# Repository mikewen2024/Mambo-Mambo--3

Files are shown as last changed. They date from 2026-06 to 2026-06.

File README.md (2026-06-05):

# Mambo - 1lb Combat Robot, Custom ESC Layout

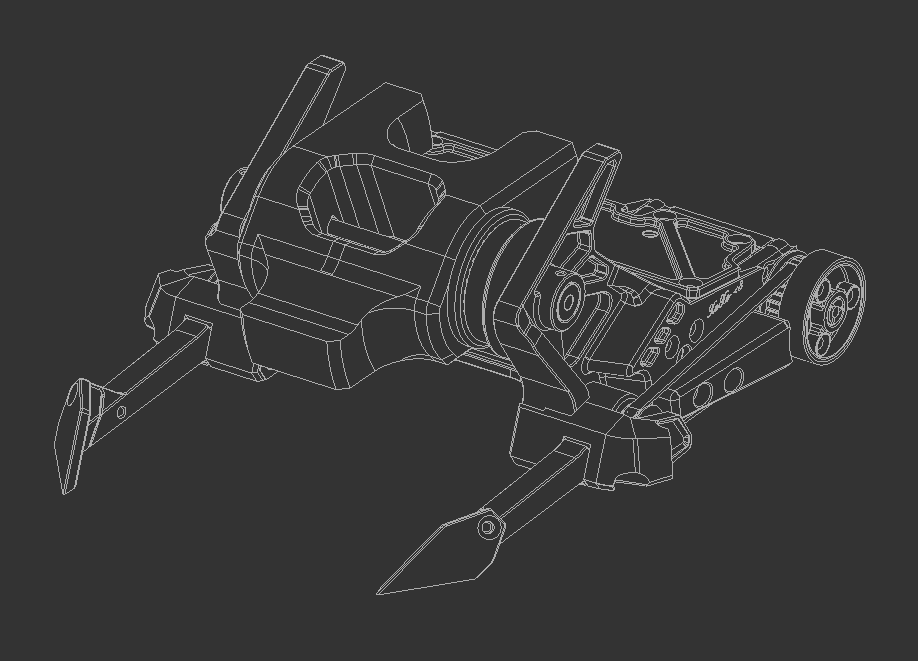
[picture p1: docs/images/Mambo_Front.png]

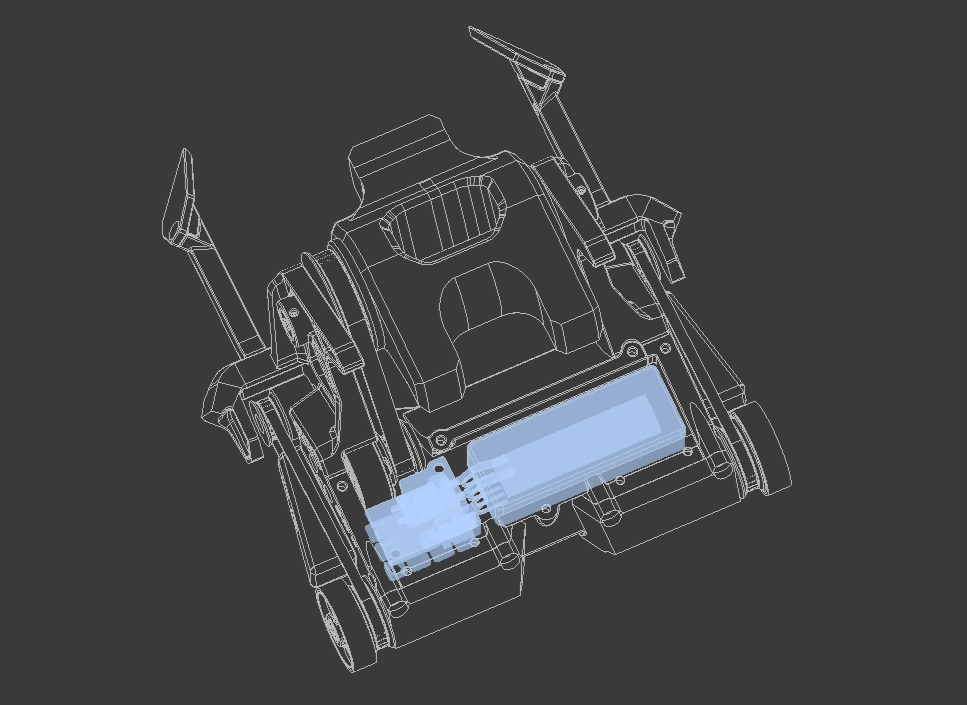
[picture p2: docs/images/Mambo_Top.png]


A 1lb plastic (plantweight) vertical spinner combat robot. I thought I'd finally try building a "meta archetype" robot after giving myself a fundamental handicap for my other 1lb combat robot projects. For the motor controller on the weapon system, there's a notable gap in the current capacities for well-known AM32-firmware BLDC motor controllers (above 35A). I also wanted to try out some alternate ESC architectures, the key features are listed below:

**Key system features:** STSPIN32F0ATR BLDC-control specific MCU (eliminates need for standalone gate driver IC), IAUC60N04S6L030H half-bridge IC for lower internal resistance, built-in TVS diodes and bulk capacitance, stable 8V 7.5A-capable output for brushed motor drivers, tight packaging and shock resistant mounting

I didn't bother making a dual brushed motor ESC for the drive system because there were already commercially-available boards that fit within my packaging constraints. Feel free to check out the corresponding technical blog [here](https://future-wool-0d5.notion.site/Mambo-1lb-Combat-Robot-375e4d628bf38082a3adc446fecd4852?pvs=74) :)

---

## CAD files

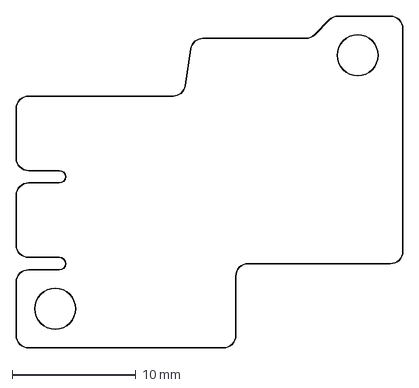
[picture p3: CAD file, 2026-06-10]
hardware/kicad/Outlines/Top PCB Outline.dxf
31.2 x 26.8 mm

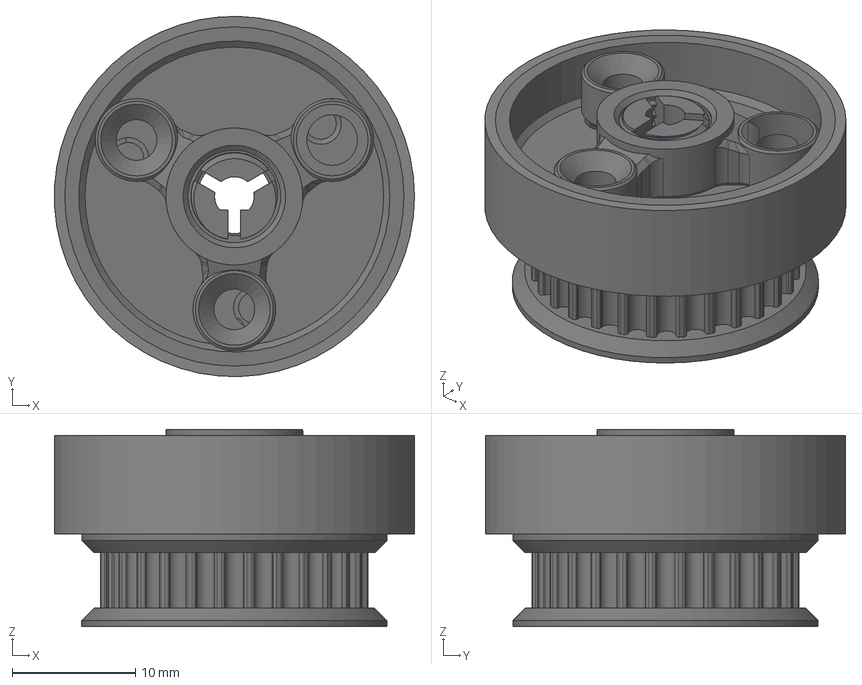
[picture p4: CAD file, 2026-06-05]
mechanical/Back Wheels.step
29.2 x 29.2 x 16.0 mm
Tightening Nut
Wheel

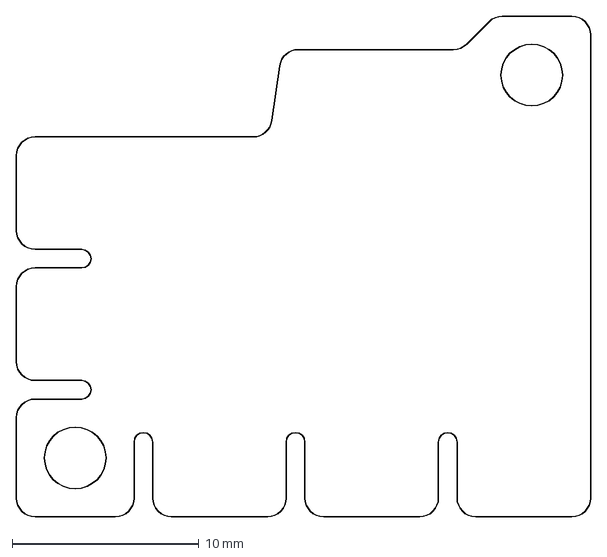
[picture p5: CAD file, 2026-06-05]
hardware/kicad/Outlines/Bottom PCB Outline.dxf
30.7 x 26.8 mm

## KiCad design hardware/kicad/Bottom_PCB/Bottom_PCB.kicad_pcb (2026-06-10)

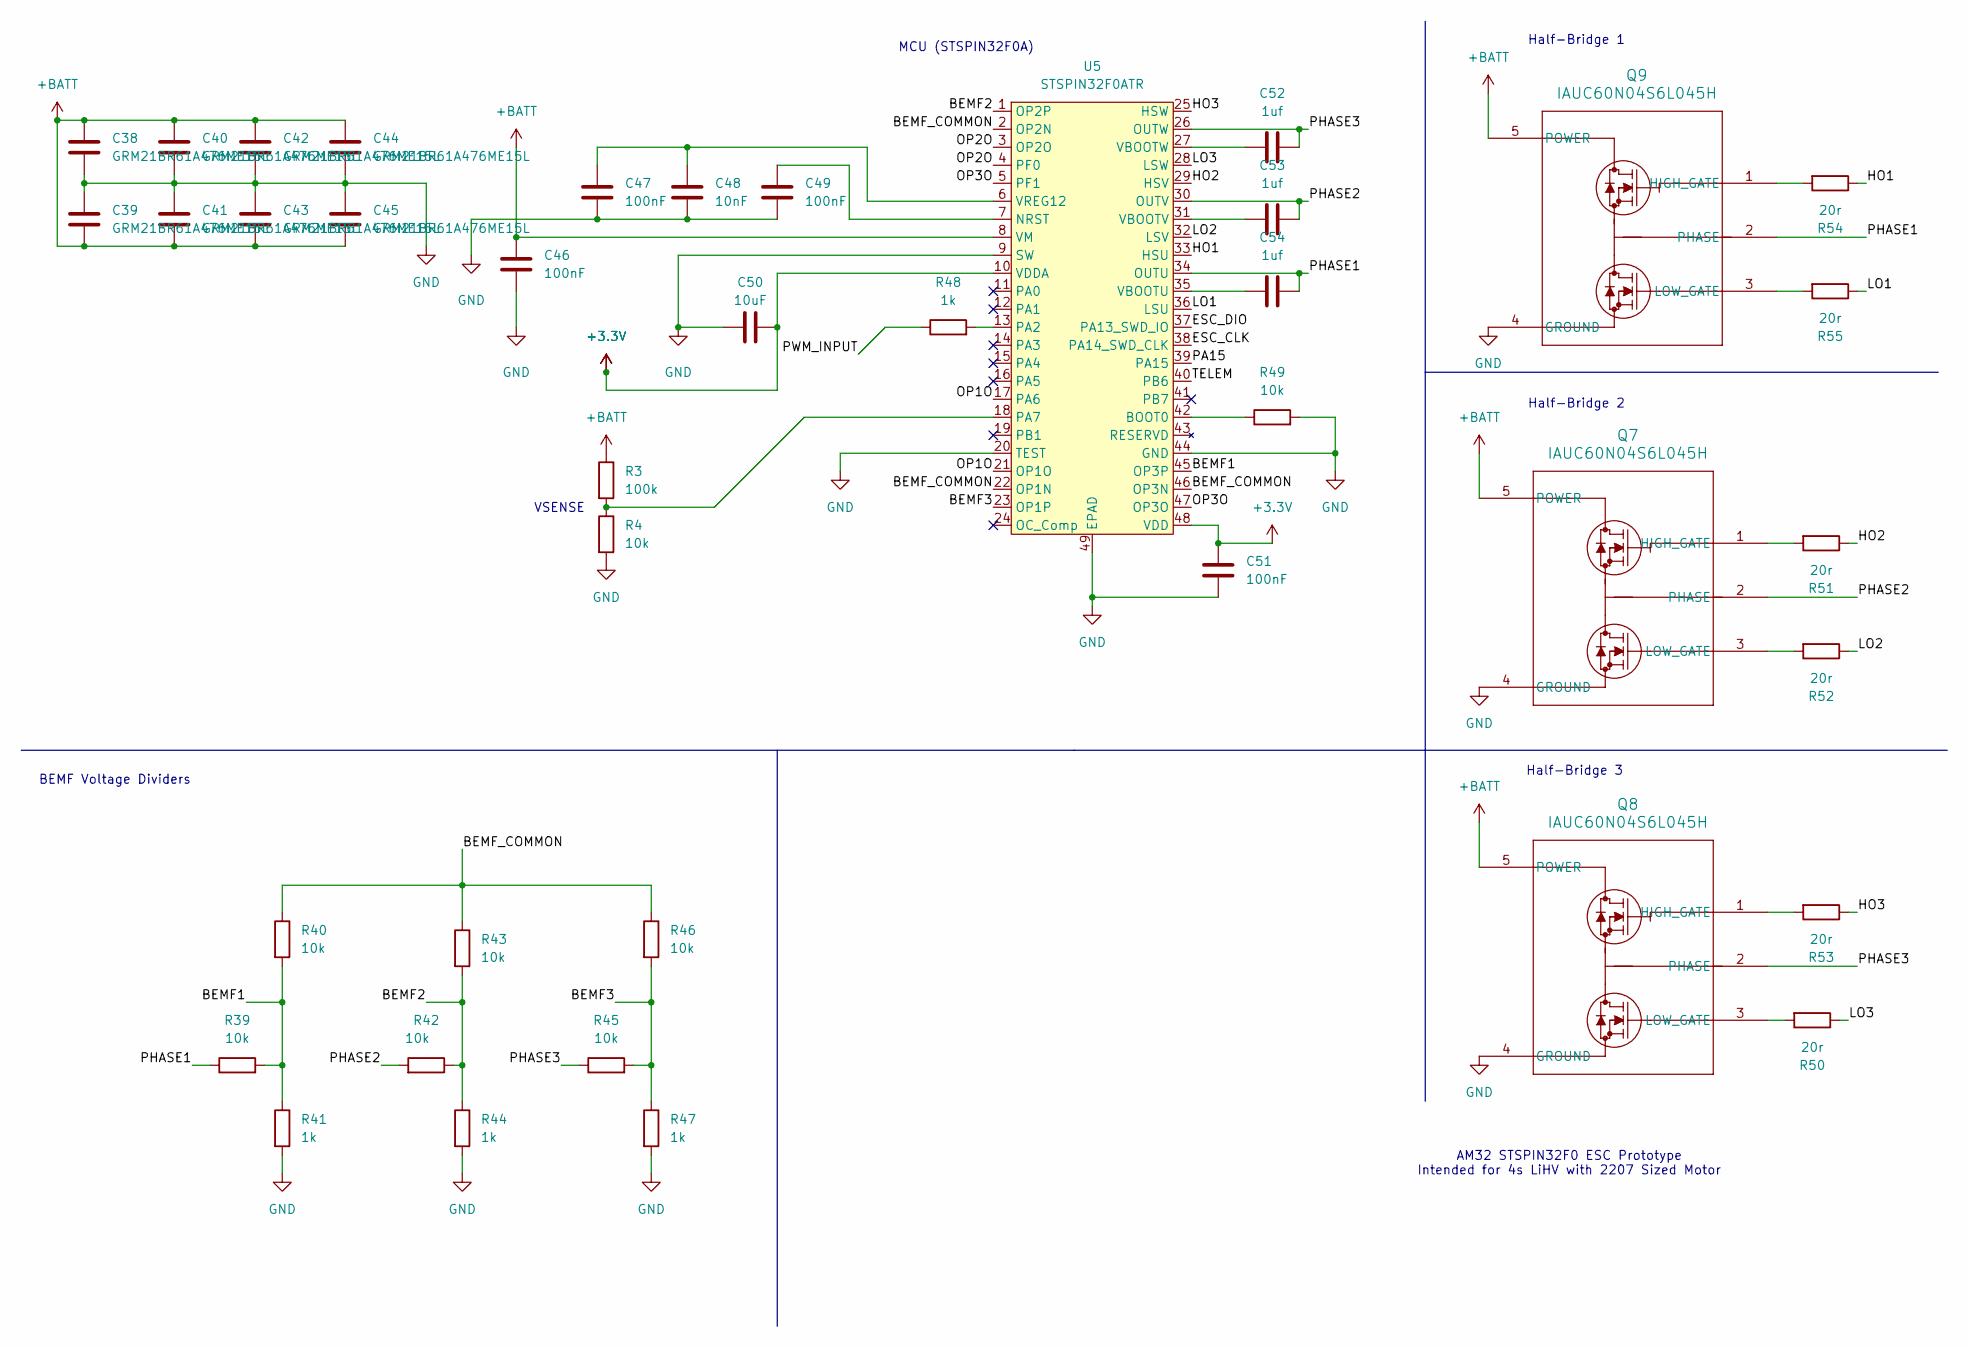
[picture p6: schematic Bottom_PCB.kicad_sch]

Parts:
C38, C39, C40, C41, C42, C43, C44, C45: GRM21BR61A476ME15L; C_0805_2012Metric
C46, C47, C49, C51: 100nF; C_0402_1005Metric_Pad0.74x0.62mm_HandSolder
C48: 10nF; C_0402_1005Metric_Pad0.74x0.62mm_HandSolder
C50: 10uF; C_0402_1005Metric_Pad0.74x0.62mm_HandSolder
C52, C53, C54: 1uf; C_0402_1005Metric_Pad0.74x0.62mm_HandSolder
Q7, Q8, Q9: IAUC60N04S6L045H; Infineon_PG-TDSON-8_56
R3: 100k; R_0402_1005Metric_Pad0.72x0.64mm_HandSolder
R4, R39, R40, R42, R43, R45, R46, R49: 10k; R_0402_1005Metric_Pad0.72x0.64mm_HandSolder
R41, R44, R47, R48: 1k; R_0402_1005Metric_Pad0.72x0.64mm_HandSolder
R50, R51, R52, R53, R54, R55: 20r; R_0402_1005Metric_Pad0.72x0.64mm_HandSolder
U5: STSPIN32F0ATR; QFN-48-1EP_7x7mm_P0.5mm_EP3.5x3.5mm

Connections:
+3.3V: C50.1, C51.1, U5.10 (VDDA), U5.48 (VDD)
+BATT: C38.1, C39.2, C40.1, C41.2, C42.1, C43.2, C44.1, C45.2, C46.1, Q7.5 (POWER), Q8.5 (POWER), Q9.5 (POWER), R3.1, U5.8 (VM)
/BEMF1: R39.2, R40.2, R41.1, U5.45 (OP3P)
/BEMF2: R42.1, R43.2, R44.1, U5.1 (OP2P)
/BEMF3: R45.2, R46.2, R47.1, U5.23 (OP1P)
/BEMF_COMMON: R40.1, R43.1, R46.1, U5.2 (OP2N), U5.22 (OP1N), U5.46 (OP3N)
/ESC_CLK: U5.38 (PA14_SWD_CLK)
/ESC_DIO: U5.37 (PA13_SWD_IO)
/HO1: R54.1, U5.33 (HSU)
/HO2: R51.1, U5.29 (HSV)
/HO3: R53.1, U5.25 (HSW)
/LO1: R55.1, U5.36 (LSU)
/LO2: R52.1, U5.32 (LSV)
/LO3: R50.1, U5.28 (LSW)
/OP1O: U5.17 (PA6), U5.21 (OP1O)
/OP2O: U5.3 (OP2O), U5.4 (PF0)
/OP3O: U5.5 (PF1), U5.47 (OP3O)
/PA15: U5.39 (PA15)
/PHASE1: C54.2, Q9.2 (PHASE), R39.1, U5.34 (OUTU)
/PHASE2: C53.2, Q7.2 (PHASE), R42.2, U5.30 (OUTV)
/PHASE3: C52.2, Q8.2 (PHASE), R45.1, U5.26 (OUTW)
/PWM_INPUT: R48.1; also elsewhere on the board
/TELEM: U5.40 (PB6)
GND: C38.2, C39.1, C40.2, C41.1, C42.2, C43.1, C44.2, C45.1, C46.2, C47.2, C48.2, C49.2, C50.2, C51.2, Q7.4 (GROUND), Q8.4 (GROUND), Q9.4 (GROUND), R4.2, R41.2, R44.2, R47.2, R49.2, U5.9 (SW), U5.20 (TEST), U5.44 (GND), U5.49 (EPAD)
unnamed: Q7.1 (HIGH_GATE), R51.2
unnamed: Q7.3 (LOW_GATE), R52.2
unnamed: Q8.1 (HIGH_GATE), R53.2
unnamed: Q8.3 (LOW_GATE), R50.2
unnamed: Q9.1 (HIGH_GATE), R54.2
unnamed: Q9.3 (LOW_GATE), R55.2
unnamed: R49.1, U5.42 (BOOT0)
unnamed: C49.1, U5.7 (NRST)
unnamed: R48.2, U5.13 (PA2)
unnamed: R3.2, R4.1, U5.18 (PA7)
unnamed: C54.1, U5.35 (VBOOTU)
unnamed: C53.1, U5.31 (VBOOTV)
unnamed: C52.1, U5.27 (VBOOTW)
unnamed: C47.1, C48.1, U5.6 (VREG12)

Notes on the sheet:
AM32 STSPIN32F0 ESC Prototype Intended for 4s LiHV with 2207 Sized Motor
BEMF Voltage Dividers
Half-Bridge 3
Half-Bridge 1
MCU (STSPIN32F0A)
VSENSE
Half-Bridge 2

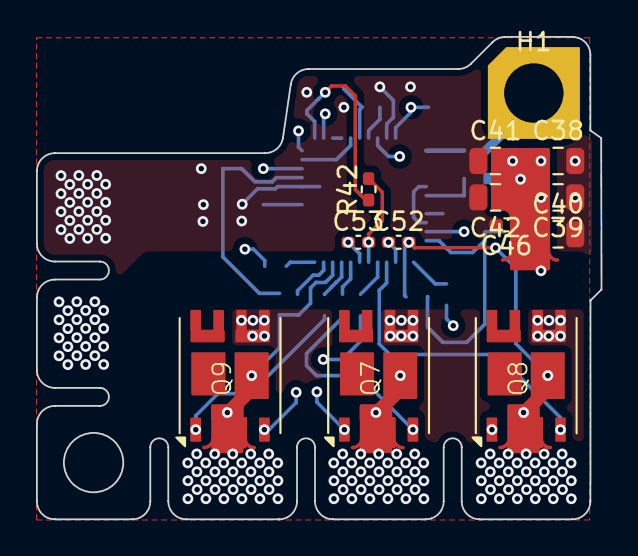
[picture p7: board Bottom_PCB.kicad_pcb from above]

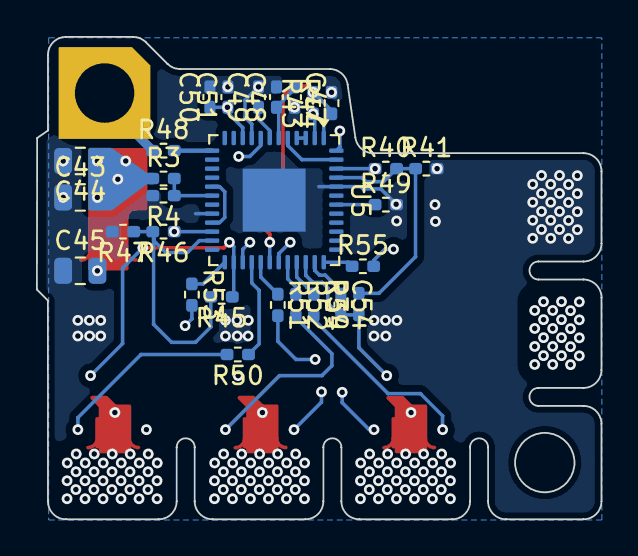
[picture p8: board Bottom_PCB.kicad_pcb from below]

Board: 4 copper layers, 31.4 x 26.8 mm, 41 parts (28 on the bottom side), 34 nets.

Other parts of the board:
H1: PWM_Input; MountingHole_2.2mm_M2_DIN965_Pad_TopBottom

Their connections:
/PWM_INPUT: H1.1; also elsewhere on the board

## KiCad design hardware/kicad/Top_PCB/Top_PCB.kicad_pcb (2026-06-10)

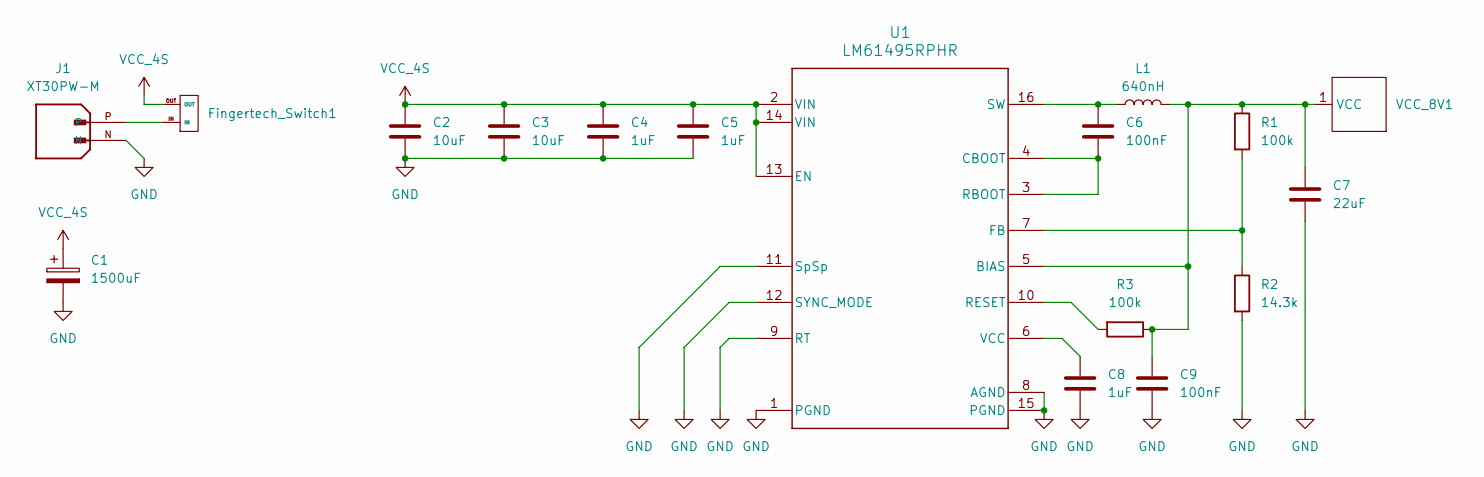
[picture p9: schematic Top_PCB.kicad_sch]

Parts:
C1: 1500uF; C_3640_9110Metric
C2, C3: 10uF; C_1206_3216Metric_Pad1.33x1.80mm_HandSolder
C4, C5, C8: 1uF; C_1206_3216Metric_Pad1.33x1.80mm_HandSolder
C6, C9: 100nF; C_1206_3216Metric_Pad1.33x1.80mm_HandSolder
C7: 22uF; C_1206_3216Metric_Pad1.33x1.80mm_HandSolder
Fingertech_Switch1: Fingertech_Switch
J1: XT30PW-M; AMASS_XT30PW-M; PARTREV 1.2
L1: 640nH; L_1206_3216Metric_Pad1.22x1.90mm_HandSolder
R1, R3: 100k; R_1206_3216Metric_Pad1.30x1.75mm_HandSolder
R2: 14.3k; R_1206_3216Metric_Pad1.30x1.75mm_HandSolder
U1: LM61495RPHR; RPH0016A
VCC_8V1: VCC_Standalone

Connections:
GND: C1.2, C2.2, C3.2, C4.2, C5.2, C7.2, C8.2, C9.2, J1.N, J1.S1, J1.S2, R2.2, U1.1 (PGND), U1.8 (AGND), U1.9 (RT), U1.11 (SpSp), U1.12 (SYNC_MODE), U1.15 (PGND)
unnamed: Fingertech_Switch1.IN, J1.P
unnamed: C7.1, C9.1, L1.2, R1.1, R3.1, U1.5 (BIAS), VCC_8V1.1 (VCC_1)
unnamed: C6.2, U1.3 (RBOOT), U1.4 (CBOOT)
unnamed: R1.2, R2.1, U1.7 (FB)
unnamed: R3.2, U1.10 (RESET)
unnamed: C6.1, L1.1, U1.16 (SW)
unnamed: C8.1, U1.6 (VCC)
VCC_4S: C1.1, C2.1, C3.1, C4.1, C5.1, Fingertech_Switch1.OUT, U1.2 (VIN), U1.13 (EN), U1.14 (VIN)

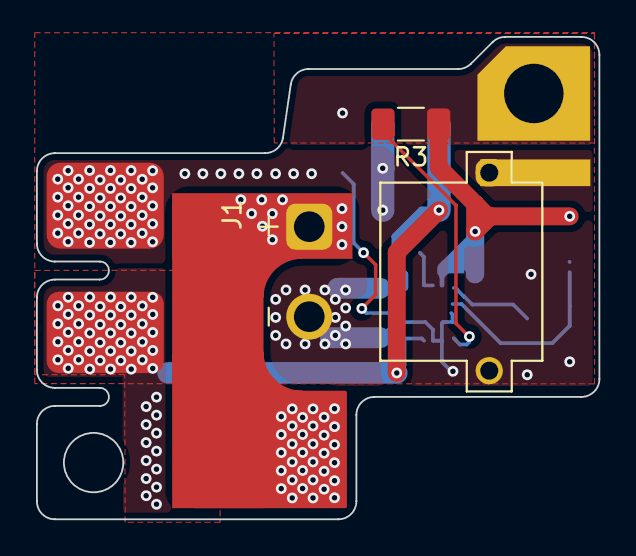
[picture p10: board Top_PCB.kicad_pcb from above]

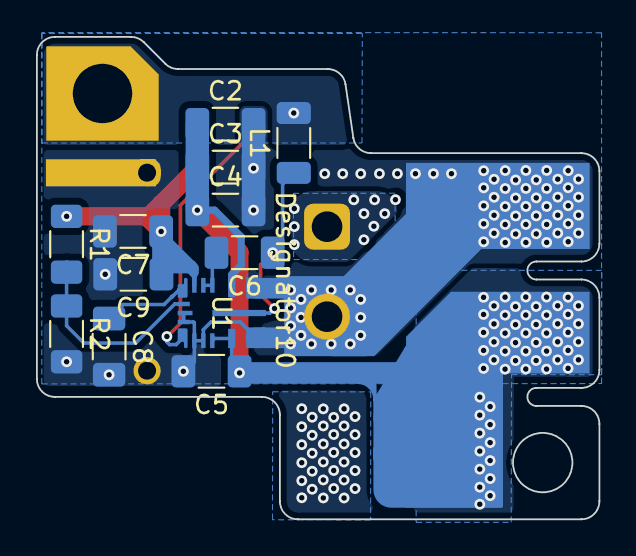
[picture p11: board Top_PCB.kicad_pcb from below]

Board: 2 copper layers, 31.2 x 26.8 mm, 17 parts (15 on the bottom side), 9 nets.

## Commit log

2026-06-05 Initial commit, PCB still being arranged as of now
    [Back Wheels.step, Bottom PCB Outline.dxf, Bottom_PCB.kicad_pcb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]
2026-06-06 Did some top board work (added regulator), added vias and refined geometry a bit
    [Top_PCB.kicad_pcb, Top_PCB.kicad_sch, bottom_board.kicad_sch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]
2026-06-10 Bottom PCB Design Checked and should be ready for review
    [Bottom_PCB.kicad_pcb, Bottom_PCB.kicad_sch, Top PCB Outline.dxf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]
